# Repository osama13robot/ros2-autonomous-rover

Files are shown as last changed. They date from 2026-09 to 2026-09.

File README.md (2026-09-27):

# ROS 2 Autonomous Rover

**Two 3D-printable robots you can simulate, drive, and watch map a house by themselves, built to learn ROS 2 from.**







| **rover**: 2WD differential drive | **rover4**: 4WD with Ackermann steering | A map built completely autonomously |
|---|---|---|
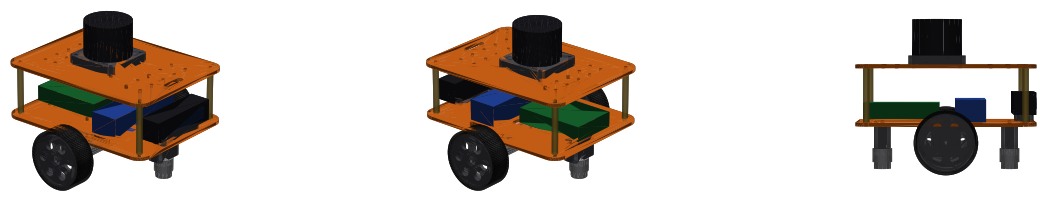
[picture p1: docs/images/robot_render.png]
rover
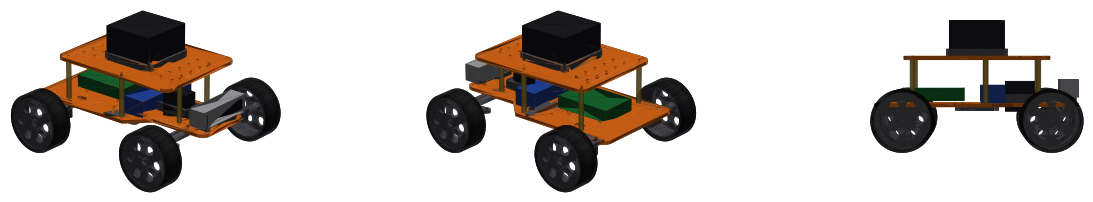
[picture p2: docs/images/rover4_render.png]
rover4
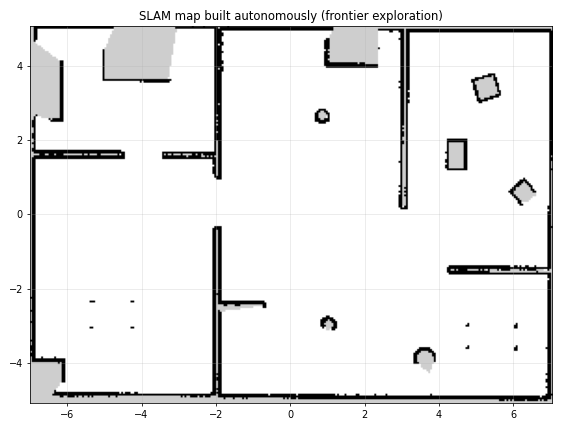
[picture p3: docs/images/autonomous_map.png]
map
|  |  |  |

This repository is a complete, working ROS 2 workspace for two small robots that share one
autonomy stack: **rover**, a 2WD differential-drive robot that turns in place, and **rover4**, a car-like
4WD robot with servo-steered front wheels, a RealSense D435i and an RPLIDAR S2M1. It covers the whole
stack, from the printable STL files to autonomous exploration, and every piece is documented so you
can understand it and change it.

## Features

| | |
|---|---|
| 🚗 **Two robots, one stack** | `robot:=rover` (2WD, turns in place) or `robot:=rover4` (4WD Ackermann steering), same topics and the same autonomy |
| 🖨️ **3D-printable hardware** | 9 + 15 printed parts generated by a parametric Python script, all fitting a 220 × 220 mm bed, with BOMs and assembly guides |
| 📐 **One source of truth** | a single `dimensions.yaml` drives the printable parts *and* the simulated robot, so they never disagree |
| 🌍 **Gazebo Harmonic simulation** | a 14 × 10 m indoor world with rooms, doorways, furniture and *low obstacles the lidar can't see* |
| 👀 **Sensors** | 360° lidar (RPLIDAR C1 / S2M1), RGB-D depth camera (RealSense D435 / D435i), IMU, wheel encoders |
| 🧭 **Localization** | EKF sensor fusion (wheel odometry + IMU), SLAM mapping, or AMCL on a saved map |
| 🗺️ **Navigation** | Nav2 with Smac planners (2D, or Hybrid-A* for the car), MPPI controller, 3D voxel costmaps that use the depth camera, and a collision monitor |
| 🤖 **Autonomous exploration** | a frontier explorer that maps unknown space by itself, then drives back home |
| 🎮 **Manual and autonomous modes** | drive with the keyboard; one key switches between MANUAL and AUTO, and any drive key takes over |
| 🧪 **Learning material** | 15 guides, 8 hands-on labs, a runnable Nav2 Python example, unit tests and CI |

## Quick start (about 15 minutes)

On **Ubuntu 24.04** with **ROS 2 Jazzy** installed ([full install guide](docs/01_installation.md)):

```bash
sudo apt install ros-jazzy-ros-gz ros-jazzy-navigation2 ros-jazzy-slam-toolbox \
  ros-jazzy-robot-localization ros-jazzy-xacro ros-jazzy-joint-state-publisher-gui python3-scipy
git clone https://github.com/osama13robot/ros2-autonomous-rover.git ~/ros2-autonomous-rover
cd ~/ros2-autonomous-rover
source /opt/ros/jazzy/setup.bash
colcon build --symlink-install
./scripts/start_sim.sh
```

Gazebo and RViz open, followed by a keyboard window. Click into the keyboard window, then:

* hold **`w a s d`** to drive
* press **`2`** to switch to **AUTO**: the robot starts exploring and mapping by itself
* press any drive key to take back control

For the 4WD car-like robot, add `robot:=rover4`: `./scripts/start_sim.sh robot:=rover4`.

Next: [Quick start guide](docs/02_quick_start.md) → [Hands-on labs](docs/10_hands_on_labs.md).

## Documentation

| # | Guide | You will learn |
|---|---|---|
| 00 | [Learning path](docs/00_learning_path.md) | where to start based on your level; glossary |
| 01 | [Installation](docs/01_installation.md) | installing ROS 2 Jazzy + Gazebo, building the workspace |
| 02 | [Quick start](docs/02_quick_start.md) | driving, going autonomous, saving and reusing maps |
| 03 | [Architecture](docs/03_architecture.md) | packages, nodes, topics, TF tree, launch files |
| 04 | [Robot design](docs/04_robot_design.md) | URDF/xacro, frames, sensors, parametric design |
| 05 | [Simulation](docs/05_simulation.md) | Gazebo worlds, plugins, the ROS bridge, sensor quirks |
| 06 | [Localization and mapping](docs/06_localization_and_mapping.md) | EKF, SLAM Toolbox, AMCL |
| 07 | [Navigation](docs/07_navigation.md) | Nav2: planner, controller, costmaps, collision monitor |
| 08 | [Manual and auto modes](docs/08_manual_and_auto_modes.md) | the velocity multiplexer and safety design |
| 09 | [Autonomous exploration](docs/09_autonomous_exploration.md) | the frontier exploration algorithm |
| 10 | [Hands-on labs](docs/10_hands_on_labs.md) | 8 guided exercises |
| 11 | [Building the real robot](docs/11_real_robot.md) | hardware bring-up, the driver topic contract |
| 12 | [Troubleshooting](docs/12_troubleshooting.md) | common problems and fixes |
| 13 | [Future possibilities](docs/13_future_possibilities.md) | a roadmap of extensions, ordered by difficulty |
| 14 | [Rover4: 4WD Ackermann](docs/14_rover4_ackermann.md) | car-like steering, Hybrid-A*, the second robot |
| – | [Hardware guide](hardware/README.md) | printable parts, BOMs, assembly, wiring (both robots) |

## Repository layout

```
ros2-autonomous-rover/          ← the repo is also the colcon workspace
├── src/
│   ├── rover_description/      robot models (rover, rover4): URDF/xacro, meshes, dimensions
│   ├── rover_gazebo/           simulation: worlds, spawning, Gazebo <-> ROS bridge
│   ├── rover_navigation/       EKF, SLAM, AMCL, Nav2 configs per robot, behavior trees, demo map
│   ├── rover_control/          Python nodes: teleop, mode manager, explorer, patrol example
│   └── rover_bringup/          top-level launch files (sim and real robot), RViz, parameters
├── hardware/                   parametric STL generator, printable parts, BOM
├── scripts/                    start_sim.sh, save_map.sh
└── docs/                       the guides listed above
```

## What has been tested

Everything below was run in simulation on the reference machine (Ubuntu 24.04, ROS 2 Jazzy,
Gazebo Harmonic 8.7, CPU-only rendering):

* **Drive base:** 0.3 m/s for 4 s gave 1.20 m of odometry; a commanded 90° turn measured 90.0°.
* **Autonomous exploration:** 131 m² mapped with no human input, then the robot drove back to the
  start. The SLAM pose was within about 1 cm of Gazebo's ground truth.
* **Saved-map navigation (AMCL):** reached a goal in another room, 6 cm from ground truth.
* **Waypoint patrol example:** all 5 waypoints across 4 rooms reached, finishing back home.
* **Low-obstacle avoidance:** the robot went around a 10 cm brick that the lidar can't see, using
  only the depth camera, with 0.41 m of clearance.
* **Mode switching:** keyboard commands pass only in MANUAL; switching to MANUAL cancels Nav2 goals; a
  drive key in AUTO takes over.
* **Unit tests:** `colcon test` passes 4 tests covering frontier detection and the velocity logic.
* **Printable parts:** all 9 + 15 STL files are verified watertight by the generator.
* **rover4 (4WD Ackermann):** measured steering angles match Ackermann geometry (25.3° / 18.9° vs. 25.5° / 19.0°
  in theory); autonomous exploration mapped 128 m² and returned home; SLAM pose within about 1 cm of ground truth.

The real-robot driver launch (`robot.launch.py`) is a **template that has not been tested on hardware**.
See [Building the real robot](docs/11_real_robot.md).

## Contributing

Contributions are welcome, from fixing a typo to adding a new world. See [CONTRIBUTING.md](CONTRIBUTING.md).

## License

[Apache License 2.0](LICENSE)

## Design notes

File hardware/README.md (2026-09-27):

# Hardware: 3D-printable parts, BOM, assembly

Two robots: the 2WD **rover** (this first section) and the 4WD Ackermann **rover4**
([jump to rover4](#rover4-4wd-ackermann)).

## Rover (2WD differential drive)

robot

A two-deck differential-drive robot, 200 × 206 × 171 mm, about 1 kg. Every structural part
fits a 220 × 220 mm print bed.

### Printable parts

The STL files are in `stl/`. They are generated from **`generate_parts.py`**, which reads
`../src/rover_description/config/dimensions.yaml`, the same file the URDF and
simulator use. Change a dimension there, then run:

```bash
python3 generate_parts.py --check   # regenerates stl/*.stl + sim meshes, verifies they are watertight
```

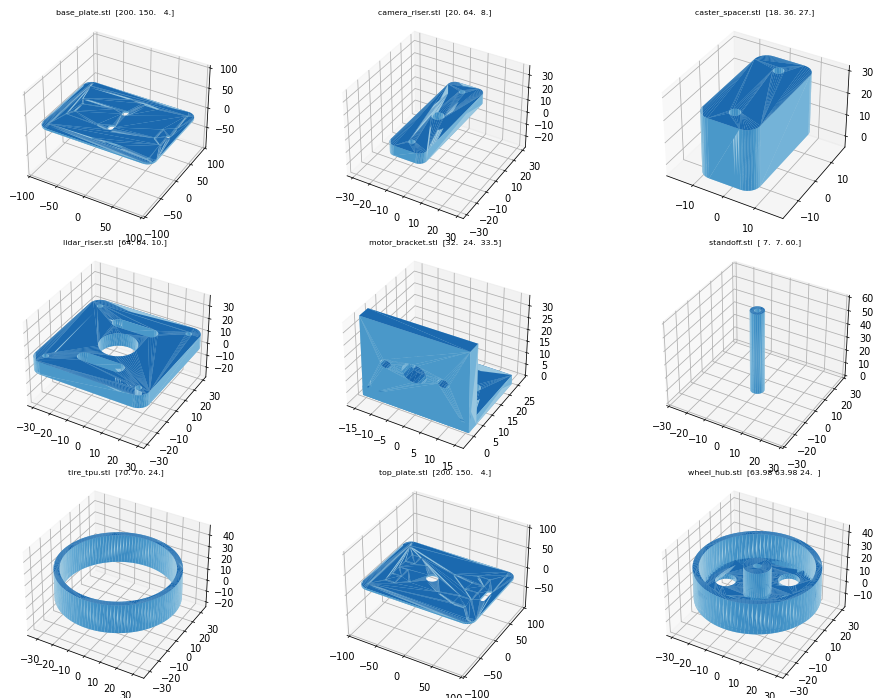
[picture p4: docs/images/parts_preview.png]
parts


| Part | Qty | Material | Notes |
|---|---|---|---|
| `base_plate.stl` | 1 | PETG / PLA | lower deck: motor brackets, casters, Pi 5, battery straps, camera riser |
| `top_plate.stl` | 1 | PETG / PLA | upper deck: lidar riser + M3 accessory grid |
| `wheel_hub.stl` | 2 | PETG | print outer face down; D-shaft press fit (4 mm JGA25 shaft) |
| `tire_tpu.stl` | 2 | TPU 95A | stretch over the hub rim |
| `motor_bracket.stl` | 2 | PETG | L-bracket, print flange down, 40 % infill |
| `caster_spacer.stl` | 2 | PETG / PLA | raises a 3/4" ball caster to the axle plane |
| `lidar_riser.stl` | 1 | PETG / PLA | |
| `camera_riser.stl` | 1 | PETG / PLA | 1/4"-20 screw from below into the camera |
| `standoff.stl` | 4 | PETG / PLA | or M3 × 60 mm brass standoffs |

Suggested print settings: 0.2 mm layers, 4 perimeters, 30 % gyroid infill, no supports.

### Bill of materials (non-printed)

| Item | Qty | Suggested part | Used for |
|---|---|---|---|
| Single-board computer | 1 | Raspberry Pi 5 (4–8 GB) + active cooler | runs ROS 2 Jazzy (Ubuntu 24.04) |
| Microcontroller | 1 | ESP32 / Raspberry Pi Pico | motor PWM + encoder counting (micro-ROS or serial) |
| Gear motors with encoders | 2 | JGA25-370, 12 V, 280 rpm, hall encoder | drive, **wheel odometry** |
| Motor driver | 1 | TB6612FNG or DRV8833 (2-channel) | |
| 2D lidar | 1 | Slamtec RPLIDAR C1 (or A1 / LDRobot LD19) | SLAM, localization, obstacles |
| RGB-D camera | 1 | Intel RealSense D435 / Luxonis OAK-D Lite | **low obstacles** the lidar can't see, images |
| IMU | 1 | BNO055 / ICM-20948 / MPU-6050 breakout | gyro for the EKF (slip-tolerant heading) |
| Ball casters | 2 | 3/4" metal ball caster (≈25 mm tall) | measure yours → `caster.body_height` |
| Battery | 1 | 3S LiPo 2200 mAh (or 3S 18650 pack + BMS) | |
| Step-down converter | 1 | 5 V / 5 A buck (USB-C PD trigger for the Pi 5) | |
| Power switch + fuse | 1 | 10 A rocker + inline 5 A fuse | |
| Screws | – | M3 × 8/10/12, M2.5 × 6 (Pi), 1/4"-20 × 8 (camera), M3 nuts / heat inserts | |

### Assembly

1. **Motors:** bolt each JGA25 gearbox face to a `motor_bracket` wall (2 × M3 × 6, 17 mm spacing).
   Bolt the bracket flanges under the base plate (2 × M3 each, holes 10 mm either side of the centre line).
2. **Wheels:** push the `tire_tpu` onto the `wheel_hub` (warm it slightly), then press the hub onto the D-shaft.
3. **Casters:** M3 screws through the base plate → `caster_spacer` → ball caster, front and rear.
4. **Electronics (lower deck, top side):** Pi 5 on M2.5 standoffs (rear), battery with a velcro
   strap through the slots (front), IMU at the centre, motor/encoder wires through the side slots.
5. **Camera:** `camera_riser` at the front edge (2 × M3), camera on the 1/4"-20 screw, facing forward.
6. **Upper deck:** 4 standoffs, then the `top_plate`; `lidar_riser` + lidar on top (cable through the centre hole).
   Motor driver, buck converter and switch go on the accessory grid.

### Wiring overview

```
3S battery ─ fuse ─ switch ─┬─ motor driver VM ── motors
                            └─ 5 V buck ── Raspberry Pi 5 ──USB── lidar
                                                   │ ├──USB3── RGB-D camera
                                                   │ └──I2C─── IMU
                                                   └──USB/UART── ESP32 ── motor driver (PWM/DIR)
                                                                   └───── encoders (A/B)
```

The ESP32 firmware must accept `/cmd_vel` and publish wheel odometry and joint states (see the
topic contract in [Building the real robot](../docs/11_real_robot.md)).

Sensor mounting positions in the URDF: lidar scan plane about 156 mm above the ground, camera
centre about 77 mm above the ground, 88 mm forward of the axle.

---

## Rover4 (4WD Ackermann)

rover4

A car-like robot: 4 driven wheels, servo-steered front wheels, RPLIDAR S2M1 and RealSense
D435i. It measures 285 × 250 × 179 mm and weighs about 2 kg. The design and the software are
explained in [docs/14](../docs/14_rover4_ackermann.md).

```bash
python3 generate_parts.py --robot rover4 --check    # → stl/rover4/*.stl (all fit a 220 × 220 mm bed)
```

Dimensions: `../src/rover_description/config/dimensions_rover4.yaml`.

### Printable parts (`stl/rover4/`)

| Part | Qty | Material | Notes |
|---|---|---|---|
| `base_rear.stl` | 1 | PETG | lower deck, rear half: rear motor clamps, Pi 5, cable slots |
| `base_front.stl` | 1 | PETG | lower deck, front half: battery straps, servo opening, beam and camera holes |
| `splice_plate.stl` | 1 | PETG | joins the two halves from below (6 × M3) |
| `top_plate.stl` | 1 | PETG / PLA | upper deck: lidar riser, accessory grid |
| `front_beam.stl` | 1 | PETG | front axle beam with the two M4 kingpin holes; 50 % infill |
| `knuckle_left.stl` / `knuckle_right.stl` | 1 + 1 | PETG | steering knuckle: kingpin boss, steering arm, N20 clamp; 5 perimeters |
| `rear_motor_clamp.stl` | 2 | PETG | N20 clamp under the rear deck |
| `servo_mount.stl` | 1 | PETG | MG996R frame; the servo shaft points down through the deck |
| `tie_rod.stl` | 2 | PETG | servo horn → steering arm |
| `wheel_hub.stl` | 4 | PETG | outer face down; 3 mm D-shaft press fit |
| `tire_tpu.stl` | 4 | TPU 95A | |
| `lidar_riser.stl` | 1 | PETG / PLA | **check the S2M1 hole pattern** (`lidar.mount_hole_spacing`) before printing |
| `camera_riser.stl` | 1 | PETG / PLA | D435i on a 1/4"-20 screw |
| `standoff.stl` | 6 | PETG / PLA | or M3 × 60 mm brass standoffs |

### Bill of materials (non-printed)

| Item | Qty | Suggested part | Used for |
|---|---|---|---|
| Single-board computer | 1 | Raspberry Pi 5, **8 GB** + active cooler | ROS 2 Jazzy; the D435i and 30 m lidar need more CPU and memory |
| Microcontroller | 1 | ESP32 (8 encoder interrupts + servo PWM) | 4 wheel speed loops, steering, odometry |
| Gear motors with encoders | 4 | N20 / GA12-N20, 12 V, ~200 rpm, hall encoder | 4-wheel drive |
| Motor drivers | 2 | TB6612FNG (2 channels each) | |
| Steering servo | 1 | MG996R (13 kg·cm) or DS3218 (20 kg·cm), metal 25T horn | front steering |
| Servo power | 1 | 6 V / 5 A UBEC | **separate supply**: the servo would brown out the Pi |
| 2D lidar | 1 | Slamtec RPLIDAR S2M1 (DFRobot), 1 Mbaud UART + USB adapter | SLAM, obstacles, 30 m range |
| RGB-D camera + IMU | 1 | Intel RealSense D435i (USB 3) | low obstacles, images, gyro for the EKF |
| Battery | 1 | 3S LiPo 2200–3000 mAh | |
| Step-down converter | 1 | 5 V / 5 A (USB-C PD for the Pi 5) | |
| Kingpins | 2 | M4 × 25 bolt + nylock nut + 2 washers | knuckle pivots |
| Tie-rod ends | 4 | M3 ball links (or M3 shoulder screws) | steering linkage |
| Screws | – | M3 × 8/10/12, M2.5 × 6 (Pi), 1/4"-20 × 8 (camera), M3 nuts / heat inserts | |

### Assembly

1. **Deck:** place `base_rear` and `base_front` edge to edge, bolt `splice_plate` underneath (6 × M3).
2. **Rear drive:** press an N20 into each `rear_motor_clamp`, bolt the clamps under the rear half (2 × M3 each).
3. **Front axle:** bolt `front_beam` under the front half (2 × M3). Press an N20 into each knuckle,
   then fit each knuckle under a beam end with an **M4 kingpin**. Tighten until it turns freely
   without play (nylock nut).
4. **Steering:** mount the servo in `servo_mount` over the deck opening, shaft down. Centre the servo
   (1500 µs) **before** fitting the horn pointing backwards. Connect the horn to both knuckle arms with the
   `tie_rod`s. Check both wheels point straight, then turn to full lock each way: **the tires must not
   touch the beam or the deck**. If they do, reduce `steering.limit` in the YAML and in the firmware.
5. **Wheels:** tires onto hubs, hubs onto the D-shafts.
6. **Electronics:** Pi 5 (rear), battery (front, strapped), ESP32 + 2 × TB6612 + UBEC on the upper
   deck grid; D435i on `camera_riser` at the nose.
7. **Upper deck:** 6 standoffs, `top_plate`, then `lidar_riser` + S2M1.

### Wiring overview

```
3S battery ─ fuse ─ switch ─┬─ 2 × TB6612 VM ── 4 × N20 motors
                            ├─ 6 V UBEC ─────── MG996R servo  (signal from ESP32)
                            └─ 5 V buck ─────── Raspberry Pi 5 ──USB── RPLIDAR S2M1
                                                       │ └─USB3── RealSense D435i (RGB-D + IMU)
                                                       └─USB── ESP32 ── 2 × TB6612 (PWM/DIR), servo PWM
                                                                  └──── 4 × encoders (A/B)
```

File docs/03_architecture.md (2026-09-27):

# 03 · Architecture

## Packages

| Package | Type | Responsibility |
|---|---|---|
| `rover_description` | CMake (data) | what the robot **is**: URDF/xacro, meshes, `dimensions.yaml` |
| `rover_gazebo` | CMake (data) | the **simulated world**: SDF worlds, spawning, Gazebo ↔ ROS bridge |
| `rover_navigation` | CMake (data) | **where am I, and how do I get there**: EKF, SLAM, AMCL, Nav2 configs and launch files |
| `rover_control` | Python | **custom behaviour**: teleop, mode manager, explorer, patrol example, sim adapter |
| `rover_bringup` | CMake (data) | **wiring it all together**: top-level launch files, RViz config, parameters |

Why split it like this? Each package can be reused alone. `rover_navigation` has no idea whether
it runs in Gazebo or on the real robot, and `rover_description` can be shown in RViz without
anything else. This is the standard ROS layout.

## Node graph

```mermaid
flowchart LR
    subgraph Gazebo["Gazebo Harmonic"]
        GZ[physics + sensors]
    end
    GZ -- "/scan" --> SLAM
    GZ -- "/camera/depth/points_raw" --> ADP[sim_sensor_adapter]
    GZ -- "/wheel/odometry, /imu" --> ADP
    ADP -- "/wheel/odometry_cov, /imu/data" --> EKF[ekf_filter_node]
    ADP -- "/camera/depth/points" --> NAV
    GZ -- "/scan" --> NAV
    EKF -- "TF odom→base_footprint<br>/odometry/filtered" --> NAV
    SLAM[slam_toolbox] -- "/map, TF map→odom" --> NAV
    SLAM -- "/map" --> EXP[frontier_explorer]
    EXP -- "navigate_to_pose (action)" --> NAV[Nav2]
    NAV -- "/cmd_vel_nav" --> MM[mode_manager]
    KEY[teleop_keyboard] -- "/cmd_vel_teleop, /mode_request" --> MM
    MM -- "/cmd_vel" --> GZ
    MM -- "/robot_mode" --> EXP
    MM -- "/robot_mode" --> KEY
```

## Topics you should know

| Topic | Type | Publisher → Subscribers |
|---|---|---|
| `/scan` | `sensor_msgs/LaserScan` | lidar → SLAM, AMCL, costmaps, collision monitor |
| `/camera/depth/points` | `sensor_msgs/PointCloud2` | sim adapter → costmaps, collision monitor |
| `/camera/color/image_raw` | `sensor_msgs/Image` | camera → RViz (and your future perception code) |
| `/imu/data` | `sensor_msgs/Imu` | sim adapter → EKF |
| `/wheel/odometry_cov` | `nav_msgs/Odometry` | sim adapter → EKF |
| `/odometry/filtered` | `nav_msgs/Odometry` | EKF → Nav2 |
| `/map` | `nav_msgs/OccupancyGrid` | SLAM / map_server → Nav2, explorer |
| `/cmd_vel_teleop` | `geometry_msgs/Twist` | keyboard → mode manager |
| `/cmd_vel_nav` | `geometry_msgs/Twist` | Nav2 collision monitor → mode manager |
| `/cmd_vel` | `geometry_msgs/Twist` | **mode manager only** → wheels |
| `/robot_mode` | `std_msgs/String` (latched) | mode manager → everyone: `MANUAL` / `AUTO` |
| `/explore/status` | `std_msgs/String` (latched) | explorer → keyboard status line |

See the live graph yourself with `rqt_graph`, and list everything with `ros2 topic list`.

## TF tree (coordinate frames)

```mermaid
flowchart TD
    map -->|"slam_toolbox or AMCL"| odom
    odom -->|"EKF (wheels + IMU)"| base_footprint
    base_footprint -->|"robot_state_publisher (URDF)"| base_link
    base_link --> left_wheel_link & right_wheel_link
    base_link --> front_caster_link & rear_caster_link
    base_link --> imu_link & lidar_link & camera_link
    camera_link --> camera_optical_link
```

* **`map → odom`**: corrects the slow drift of odometry. It can *jump* when SLAM closes a loop.
* **`odom → base_footprint`**: smooth and continuous, but drifts over time. Controllers use this.
* **`base_footprint`** is on the ground under the robot centre; **`base_link`** is on the wheel axle.

This split is the ROS convention [REP-105](https://www.ros.org/reps/rep-0105.html). See it live with
`ros2 run tf2_tools view_frames` (it writes `frames.pdf`).

## The velocity chain (who is allowed to move the robot)

```
Nav2 controller ──cmd_vel_nav_raw──► velocity_smoother ──cmd_vel_smoothed──► collision_monitor ──cmd_vel_nav──┐
                                                                                                               ├─► mode_manager ──cmd_vel──► wheels
teleop_keyboard ──cmd_vel_teleop───────────────────────────────────────────────────────────────────────────────┘
```

Exactly **one** node (`mode_manager`) writes `/cmd_vel`. This single point of control is what makes
the manual/auto switch safe and simple. See [08 Manual and auto modes](08_manual_and_auto_modes.md).

## Launch file hierarchy

```
rover_bringup/sim.launch.py                   ← what you run for simulation
├── rover_gazebo/sim.launch.py                   Gazebo + spawn + bridge + robot_state_publisher
├── rover_control sim_sensor_adapter             (node)
└── rover_bringup/autonomy.launch.py          ← shared with the real robot
    ├── rover_navigation/ekf.launch.py
    ├── rover_navigation/slam.launch.py          (if slam:=true)
    ├── rover_navigation/localization.launch.py  (if slam:=false: map_server + AMCL)
    ├── rover_control mode_manager               (node)
    ├── rviz2                                    (if rviz:=true)
    └── after 3 s: rover_navigation/navigation.launch.py (Nav2) + frontier_explorer

rover_bringup/robot.launch.py                 ← what you run on the real robot
├── robot_state_publisher, lidar driver, camera driver
└── rover_bringup/autonomy.launch.py
```

## Configuration files

| File | Controls |
|---|---|
| `rover_description/config/dimensions.yaml` | every physical dimension, mass and sensor spec |
| `rover_gazebo/config/gz_bridge.yaml` | which Gazebo topics are bridged to ROS |
| `rover_navigation/config/ekf.yaml` | sensor fusion |
| `rover_navigation/config/slam_toolbox.yaml` | mapping |
| `rover_navigation/config/nav2_params.yaml` | planning, control, costmaps, AMCL, safety |
| `rover_bringup/config/control.yaml` | mode manager, explorer, sim adapter |

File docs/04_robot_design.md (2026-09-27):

# 04 · Robot design

robot

## Concept

A classic **two-deck differential-drive** robot, the same layout as TurtleBot-style platforms:

* two driven wheels on a common axle at the centre, so it can **turn in place**
* front and rear ball casters for balance
* a lower deck for motors, battery and computer, and an upper deck for the lidar (clear 360° view)
* an RGB-D camera low at the front, where it sees what the lidar misses

| Property | Value |
|---|---|
| Size (L × W × H) | 200 × 206 × 171 mm |
| Mass | ~1 kg |
| Wheel radius / separation | 35 mm / 182 mm |
| Top speed (sim limit) | 0.5 m/s, autonomy uses ≤ 0.35 m/s |
| Lidar scan height | 156 mm |
| Camera height | 77 mm, 88 mm ahead of the axle |

## One source of truth: `dimensions.yaml`

`src/rover_description/config/dimensions.yaml` holds every dimension, mass and sensor setting.
Two very different programs read it:

```
dimensions.yaml ──► rover.urdf.xacro ──► simulation, TF frames, Nav2
               └──► hardware/generate_parts.py ──► printable STL files (+ meshes shown in the sim)
```

So if you make the wheels bigger, both the printed parts and the simulated robot change together.
This is the most important design idea in the project: **the model can't drift away from the real robot**.

In xacro, the YAML is loaded with:

```xml
<xacro:property name="d" value="${xacro.load_yaml('$(find rover_description)/config/dimensions.yaml')}"/>
<xacro:property name="R" value="${d['wheel']['radius']}"/>
```

## URDF structure

`urdf/rover.urdf.xacro` is organised as:

| Block | Contents |
|---|---|
| properties | derived heights (all relative to the wheel axle), wheel positions |
| `base_link` | both decks (STL meshes), standoffs, motors, electronics; **one** simple box for collision |
| `wheel` macro | a continuous joint about Y; visual = printed hub + tire meshes, collision = cylinder |
| `caster` macro | fixed sphere with **zero friction**, so it slides like a free ball |
| sensors | `imu_link`, `lidar_link`, `camera_link` + `camera_optical_link` |
| `rover.gazebo.xacro` | simulation-only plugins and sensors (included when `sim_gazebo:=true`) |

Design choices worth noticing:

* **Visual and collision geometry are different.** Visuals use detailed meshes (they look good);
  collisions use boxes, cylinders and spheres, which are fast and stable for the physics engine.
* **Inertia is computed by macros** (`inertial_macros.xacro`) from mass and size. Wrong inertia is a
  classic cause of robots that shake or fly away in simulation.
* **`camera_optical_link`** is rotated so that Z points forward, X right and Y down. This is the
  convention for camera images ([REP-103](https://www.ros.org/reps/rep-0103.html)); robot bodies use
  X forward, Y left, Z up.

## Sensors

| Sensor | Real part | Simulated as | Why it's there |
|---|---|---|---|
| 2D lidar | RPLIDAR C1 | `gpu_lidar`, 360 samples, 0.12–12 m, 10 Hz, σ = 1 cm | SLAM and localization need long-range 360° geometry |
| RGB-D camera | RealSense D435 | `rgbd_camera`, 424 × 240, 87° FOV, 0.2–6 m, 15 Hz | the lidar is a single plane at 15.6 cm, so the camera catches **lower and higher** obstacles |
| IMU | BNO055 / ICM-20948 | `imu`, 100 Hz, realistic noise and bias | its gyro measures rotation directly, even when the wheels slip |
| Wheel encoders | JGA25-370 hall encoders | `DiffDrive` odometry + `JointStatePublisher` | measure distance travelled; the backbone of odometry |

Each sensor covers a weakness of another:

* **Wheel odometry** is accurate over short distances but drifts, and it is wrong when a wheel slips.
* The **IMU gyro** is right during slips but drifts in heading over time.
* **Lidar SLAM** corrects long-term drift, but it only sees one horizontal plane.
* The **depth camera** sees in 3D, but only forward and at short range.

Combining them (sensor fusion) gives a system more reliable than any single sensor.

## Viewing and editing the robot

```bash
ros2 launch rover_description display.launch.py                  # with STL meshes
ros2 launch rover_description display.launch.py use_meshes:=false  # simple shapes
xacro src/rover_description/urdf/rover.urdf.xacro > /tmp/rover.urdf && check_urdf /tmp/rover.urdf
```

After changing `dimensions.yaml`:

```bash
python3 hardware/generate_parts.py --check   # new STL parts + sim meshes
colcon build --symlink-install               # meshes are installed files
```

Lab 1 in [Hands-on labs](10_hands_on_labs.md) walks you through this.

## Printable hardware

See the [Hardware guide](../hardware/README.md) for the parts list, BOM, print settings, assembly and wiring.

parts

The parts generator is itself a small lesson in computational geometry. Every part is a set of
**2.5D extrusions** (a 2D outline with holes, pushed up to a thickness). The script triangulates each
outline with **ear clipping** (holes are joined to the outline with "bridge" edges), builds the walls
and writes binary STL. `--check` verifies that every edge is shared by exactly two triangles, which
means the part is watertight and printable.

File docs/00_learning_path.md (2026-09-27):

# 00 · Learning path

This project is designed so you can learn from it in layers. First you run it and see it work,
then you understand how it works, then you change it.

## Who this is for

| You are… | Start with | Then |
|---|---|---|
| **New to ROS 2** (you know some Python and Linux) | [01 Installation](01_installation.md) → [02 Quick start](02_quick_start.md) | Labs 1–3, then guides 03 and 04 |
| **Familiar with ROS 2 basics** (nodes, topics, launch) | [02 Quick start](02_quick_start.md) → [03 Architecture](03_architecture.md) | Guides 06–09, then labs 4–7 |
| **Experienced with ROS / Nav2** | [03 Architecture](03_architecture.md) | [13 Future possibilities](13_future_possibilities.md): pick a project |
| **A maker who wants to build it** | [Hardware guide](../hardware/README.md) | [11 Real robot](11_real_robot.md), [14 Rover4](14_rover4_ackermann.md) |
| **Curious about car-like robots** | [14 Rover4: 4WD Ackermann](14_rover4_ackermann.md) | compare with guides 07 and 09 |
| **A teacher** | This page + [10 Hands-on labs](10_hands_on_labs.md) | Each lab is one class session (45–90 min) |

## Prerequisites

* **Computer:** Ubuntu 24.04, 4+ CPU cores, 8 GB RAM (16 GB recommended). A GPU helps a lot but is
  not required: the whole project was developed and tested with CPU-only rendering.
* **Skills:** basic terminal use (`cd`, `ls`, editing files) and reading Python. No robotics
  background is needed; concepts are explained as they come up.

## Suggested 4-week course

| Week | Topic | Guides | Labs |
|---|---|---|---|
| 1 | Run it, drive it, explore the ROS graph | 01, 02, 03 | 1, 2, 3 |
| 2 | Robot description and simulation | 04, 05 | (edit the robot in Lab 1) |
| 3 | Localization, mapping, navigation | 06, 07 | 4, 5, 6 |
| 4 | Autonomy and your own code | 08, 09 | 7, 8 + a project from guide 13 |

## How the pieces fit together (the 60-second version)

1. **Sensors** (lidar, depth camera, IMU, wheel encoders) publish data on **topics**.
2. An **EKF** fuses wheel odometry and IMU into a smooth estimate of how the robot moved.
3. **SLAM** uses the lidar to build a **map** and to work out where the robot is on it.
4. **Nav2** plans a path on that map and drives the robot along it while avoiding obstacles.
5. The **frontier explorer** picks the next unexplored spot and gives it to Nav2 as a goal.
6. The **mode manager** decides who is allowed to drive: you (keyboard) or Nav2.

## Glossary

| Term | Meaning |
|---|---|
| **Node** | a running program in ROS 2 (for example `mode_manager`) |
| **Topic** | a named data stream nodes publish to and subscribe from (for example `/scan`) |
| **Service** | a request/response call (for example `/set_autonomous`) |
| **Action** | a long-running goal with feedback and cancel (for example `navigate_to_pose`) |
| **TF** | the tree of coordinate frames (`map → odom → base_footprint → lidar_link …`) |
| **URDF / xacro** | XML description of the robot's links, joints, sensors; xacro adds variables and macros |
| **Odometry** | an estimate of motion from wheels/IMU; it drifts slowly over time |
| **EKF** | Extended Kalman Filter: combines noisy sensors into a better estimate |
| **SLAM** | Simultaneous Localization And Mapping: building a map while locating yourself in it |
| **AMCL** | Adaptive Monte Carlo Localization: locating the robot on an *existing* map using particles |
| **Costmap** | a grid saying how "expensive" (dangerous) each cell is for the robot |
| **Frontier** | the border between explored free space and unknown space |
| **Lifecycle node** | a node with managed states (unconfigured → inactive → active); Nav2 uses these |
| **Sim time** | in simulation, nodes use Gazebo's clock (`/clock`) instead of the wall clock |

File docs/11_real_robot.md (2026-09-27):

# 11 · Building the real robot

> This guide uses the 2WD **rover**; for **rover4** add `robot:=rover4` to the launch commands and see
> [14 Rover4](14_rover4_ackermann.md#real-robot-firmware-for-ackermann) for the steering firmware.

> **Status:** the mechanical design and the autonomy stack are complete and tested *in simulation*.
> The hardware bring-up described here is a **plan and a template**: the driver launch file has not
> been run on physical hardware yet. Contributions from people who build it are very welcome.

## 1. Build the hardware

Follow the [Hardware guide](../hardware/README.md): print the parts, buy the BOM, assemble and wire.
**Before printing**, measure your actual ball casters, motors and sensors, update
`dimensions.yaml`, and regenerate the parts.

## 2. Set up the computer (Raspberry Pi 5)

* Install **Ubuntu Server 24.04** (64-bit) and **ROS 2 Jazzy** (`ros-jazzy-ros-base` is enough on
  the robot; run RViz on your laptop).
* Clone this repository and build it (skip `rover_gazebo` to save time):
  `colcon build --symlink-install --packages-skip rover_gazebo`.
* Put the robot and the laptop on the same network with the same `ROS_DOMAIN_ID`.

## 3. The driver topic contract

The autonomy stack (`rover_bringup/autonomy.launch.py`) is exactly the same in simulation and on
the real robot. It expects these topics, which the drivers must provide:

| Direction | Topic | Type | Requirements |
|---|---|---|---|
| publish | `/scan` | `sensor_msgs/LaserScan` | `frame_id: lidar_link` |
| publish | `/camera/depth/points` | `sensor_msgs/PointCloud2` | frame must exist in the TF tree |
| publish | `/imu/data` | `sensor_msgs/Imu` | `frame_id: imu_link`, fill covariances; orientation covariance `[-1, …]` if there is no magnetometer |
| publish | `/wheel/odometry_cov` | `nav_msgs/Odometry` | twist from the encoders, `odom → base_footprint`, realistic twist covariance, **no TF** (the EKF publishes it) |
| publish | `/joint_states` | `sensor_msgs/JointState` | `left_wheel_joint`, `right_wheel_joint` positions in radians |
| subscribe | `/cmd_vel` | `geometry_msgs/Twist` | stop the motors if no message arrives for 0.5 s |

In simulation, Gazebo + `sim_sensor_adapter` provide exactly this contract.

## 4. Lidar and camera drivers

```bash
sudo apt install ros-jazzy-sllidar-ros2 ros-jazzy-realsense2-camera
ros2 launch rover_bringup robot.launch.py lidar:=true camera:=true
```

`robot.launch.py` configures:

* **sllidar_ros2** (RPLIDAR C1: 460800 baud, `frame_id: lidar_link`)
* **realsense2_camera** (424 × 240 at 15 Hz, point cloud on, its own TF off)

Check the frames the camera actually publishes: `ros2 topic echo --once /camera/depth/points --field header`.
If the frame (for example `camera_depth_optical_frame`) isn't in the URDF, either add it as a child
of `camera_link` in `rover.urdf.xacro`, or set the driver's frame parameters to match.

## 5. Motor controller firmware (to be written)

The microcontroller (ESP32 or Raspberry Pi Pico) needs to:

1. read both encoders (quadrature, interrupts or the PCNT peripheral on the ESP32),
2. run a **PID speed loop** per wheel (typically 50–100 Hz),
3. convert `/cmd_vel` → wheel speeds:
   `v_left = v − ω·L/2`, `v_right = v + ω·L/2` (L = 0.182 m, wheel radius 0.035 m),
4. integrate wheel travel into odometry and publish `/wheel/odometry_cov` and `/joint_states`,
5. apply the 0.5 s command timeout (safety).

Two common ways to connect it:

* **micro-ROS** on the ESP32: it becomes a ROS 2 node directly (USB serial or Wi-Fi via the
  `micro_ros_agent`).
* **A serial protocol** plus a small Python bridge node on the Pi: simpler to debug.

## 6. Bring-up checklist

| Step | Check |
|---|---|
| Wheels | `ros2 topic pub /cmd_vel …` with 0.1 m/s: both wheels turn forward |
| Encoders | push the robot by hand 1 m: `/wheel/odometry_cov` says about 1 m |
| Turning | command 1 rad/s for 6.28 s: the robot turns one full circle |
| IMU | rotate by hand: `/imu/data` `angular_velocity.z` is positive counter-clockwise |
| Lidar | RViz, fixed frame `base_footprint`: walls appear where they really are |
| TF | `ros2 run tf2_tools view_frames` matches [03 Architecture](03_architecture.md#tf-tree-coordinate-frames) |
| EKF | drive a square: `/odometry/filtered` returns close to the start |
| SLAM | map a room slowly in MANUAL |
| Nav2 | send short goals first, with `vx_max` reduced to 0.15 |
| Safety | lift the robot, then kill the teleop: the wheels must stop within 0.5 s |

## 7. Calibration

* **Wheel radius:** drive 2 m straight and measure; scale the radius by `actual / reported`.
* **Wheel separation:** spin 10 turns in place and compare with the reported angle; scale the
  separation the same way.
* **IMU:** keep the robot still at start-up for the gyro bias estimate (BNO055 does this internally).
* **Camera extrinsics:** make sure the camera pose in `dimensions.yaml` matches the real mount.
  Place a box in front of the robot and check that the point cloud and the lidar agree in RViz.

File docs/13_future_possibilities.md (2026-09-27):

# 13 · Future possibilities

The rover is a platform. Here are directions to take it, from weekend projects to research topics.
Each one lists what you'd learn and where to start in the code.

Difficulty: 🟢 beginner · 🟡 intermediate · 🔴 advanced

## Perception

| Project | | What you'd build | Starting point |
|---|---|---|---|
| **Object detection** | 🟡 | run a YOLO model on `/camera/color/image_raw`, publish `vision_msgs/Detection2DArray` | a new node; the camera is already bridged |
| **3D object positions** | 🟡 | combine detections with the depth image, so the robot knows *where* a chair is | depth is on `/camera/depth/image_raw` |
| **Semantic map** | 🔴 | label map regions ("kitchen", "door") from detections | a new costmap layer, or markers |
| **Person following** | 🟡 | detect a person, send moving goals, or drive directly in AUTO | `waypoint_patrol.py` is the template |
| **ArUco / AprilTag docking** | 🟡 | find a tag on a charging dock and drive onto it precisely | Nav2's `opennav_docking` is installed with Nav2 |
| **Cliff detection** | 🟢 | treat a *missing* floor in the depth image as an obstacle (stairs!) | extend the depth pipeline in `sim_sensor_adapter` |

## Mapping and localization

| Project | | What you'd build | Starting point |
|---|---|---|---|
| **3D RGB-D SLAM** | 🔴 | RTAB-Map with the depth camera for 3D maps and visual loop closure | `ros-jazzy-rtabmap-ros`, replace `slam.launch.py` |
| **Lifelong mapping** | 🟡 | keep updating a saved map as furniture moves | SLAM Toolbox `lifelong` mode |
| **Multi-floor maps** | 🔴 | switch maps when changing floor | Nav2 map server `load_map` service |
| **Better exploration** | 🟡 | information-gain frontiers, planner-based distances | `frontier_explorer.py`, see guide 09 |

## Navigation and behaviour

| Project | | What you'd build | Starting point |
|---|---|---|---|
| **Patrol scheduler** | 🟢 | patrol routes at set times, with a report of what was seen | `waypoint_patrol.py` |
| **Custom behavior tree** | 🟡 | a Nav2 BT XML, for example "try the goal; if blocked, wait 10 s, then try another route" | `bt_navigator` `default_nav_to_pose_bt_xml` |
| **Keepout / speed zones** | 🟢 | forbid areas and slow down near people | Nav2 costmap filters (a mask image) |
| **Assisted teleop mode** | 🟢 | keyboard driving that refuses to crash | Nav2 `assisted_teleop`, `mode_manager.py` |
| **Gamepad control** | 🟢 | `teleop_twist_joy` → `/cmd_vel_teleop`, a button → `/mode_request` | guide 08 |
| **Return to charge** | 🟡 | a battery model: when low, go to the dock | a battery plugin in Gazebo + docking |

## Interfaces

| Project | | What you'd build | Starting point |
|---|---|---|---|
| **Web dashboard** | 🟡 | map, camera, mode buttons in a browser (phone-friendly) | `rosbridge_suite` + roslibjs, or Foxglove |
| **Voice / natural-language commands** | 🟡 | "go to the kitchen", with a language model turning text into goals | named places → poses → `goToPose` |
| **Telemetry and logging** | 🟢 | record runs with `ros2 bag record`, analyse them offline | `ros2 bag` |

## Engineering

| Project | | What you'd build | Starting point |
|---|---|---|---|
| **Docker dev container** | 🟢 | one command to get a working environment on any OS | an `osrf/ros:jazzy-desktop-full` base image |
| **Simulation tests in CI** | 🟡 | a headless test that explores the world and checks the map area | the CI workflow in `.github/workflows` |
| **ros2_control** | 🟡 | replace the Gazebo DiffDrive plugin with `diff_drive_controller`, the same controller used on real hardware | `gz_ros2_control` is available |
| **C++ ports** | 🟡 | rewrite `mode_manager` in C++ (composable node) for lower latency | a good C++ ROS 2 exercise |
| **Parameter sweeps** | 🟡 | automatically run exploration with many parameter sets and compare | Lab 7, automated |

## Hardware

| Project | | What you'd build |
|---|---|---|
| **Bumper ring** | 🟢 | printed bumper + microswitches → a `/bumper` topic → an emergency stop |
| **Battery monitor** | 🟢 | an INA219 current/voltage sensor → `sensor_msgs/BatteryState` |
| **Outdoor variant** | 🔴 | bigger wheels, GPS + `navsat_transform`, outdoor Nav2 |
| **Small arm** | 🔴 | a 3-DOF printed arm on the top deck, with MoveIt 2 |
| **Mecanum wheels** | 🟡 | a holonomic drive: MPPI `motion_model: Omni` |
| **Per-wheel speeds for rover4** | 🟡 | drive each of the 4 wheels at its own Ackermann speed in simulation too (ros2_control `ackermann_steering_controller` or a custom Gazebo system), removing tire scrub |
| **4-wheel steering (rover4 → 4WS)** | 🔴 | steer the rear axle as well: tighter turns, crab motion; needs a custom controller and planner model |

## Research directions

* **Reinforcement learning** for local navigation, trained in this Gazebo world (a gym wrapper
  around `/cmd_vel` and `/scan`).
* **Multi-robot exploration**: several rovers, namespaced, sharing a map and splitting frontiers.
* **Sim-to-real studies**: measure how parameters tuned in simulation transfer to the real robot,
  and add noise and latency models to close the gap.
* **Learning-based perception for costmaps**: learn which depth points are traversable
  (thick carpet vs. a real step).

## Contributing a project

Pick one, open an issue saying you're working on it, and see [CONTRIBUTING.md](../CONTRIBUTING.md).
Add a guide in `docs/` for anything you build. Future learners will thank you.

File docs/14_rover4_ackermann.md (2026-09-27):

# 14 · Rover4: 4WD with Ackermann steering

rover4

Rover4 is the second robot in this repository: a **car-like** robot with **all four wheels driven**
and the **front wheels steered** by one servo. It uses a **RealSense D435i** (RGB-D + IMU) and an
**RPLIDAR S2M1** (30 m range). Everything else is shared with the 2WD rover: the autonomy stack,
mode switching, exploration, the docs and the labs. Select it with `robot:=rover4`.

```bash
./scripts/start_sim.sh robot:=rover4                    # simulation + car-mode keyboard
./scripts/start_sim.sh robot:=rover4 initial_mode:=auto # explore by itself right away
ros2 launch rover_description display.launch.py robot:=rover4   # model + steering sliders in RViz
```

## Rover vs. Rover4

| | rover (2WD) | rover4 (4WD Ackermann) |
|---|---|---|
| Drive | 2 wheels, differential | 4 wheels driven (N20 motors) |
| Steering | by wheel speed difference | front wheels, one MG996R servo |
| Turn in place | ✅ | ✖ (min. turning radius ≈ 0.35 m) |
| Size (L × W × H) | 200 × 206 × 171 mm | 285 × 250 × 179 mm |
| Wheels | Ø70 mm | Ø85 mm |
| Lidar | RPLIDAR C1 (12 m) | RPLIDAR S2M1 (30 m, DTOF) |
| Depth camera | RealSense D435 | RealSense D435i |
| IMU | separate board | the D435i's built-in BMI055 |
| Reference frame | axle centre | **rear**-axle centre |
| Global planner | Smac 2D | **Smac Hybrid-A\*** (Reeds-Shepp) |
| Controller | MPPI DiffDrive | **MPPI Ackermann** |
| Behavior tree | Nav2 default | default **without Spin** |
| Printed parts | 9 designs | 15 designs |

## Ackermann steering in 3 minutes

When a car turns, all wheels must roll around **one common centre** on the line of the rear
axle, otherwise the tires scrub sideways. That means the **inner front wheel must steer more** than
the outer one:

```
          δ_inner = atan( L / (R − k/2) )        L = wheelbase   (0.200 m)
          δ_outer = atan( L / (R + k/2) )        k = kingpin distance (0.160 m)
                                                 R = turn radius of the rear-axle centre
```

The knuckles' **steering arms point towards the rear-axle centre**. With one tie rod per side,
this linkage produces roughly this unequal angle automatically; that's the "Ackermann geometry".

A velocity command `(v, ω)` becomes a turn radius `R = v / ω`. That's why a car can't turn in place:
for `v = 0`, `R = 0`, which would need infinite steering. The steering limit (30°) gives the
minimum radius `R_min = L / tan(30°) ≈ 0.35 m`; the navigation stack uses 0.40 m for margin.

**Measured in simulation** (turning with R = 0.5 m): inner wheel **25.3°**, outer **18.9°**;
the formula above gives 25.5° and 19.0°.

## Hardware

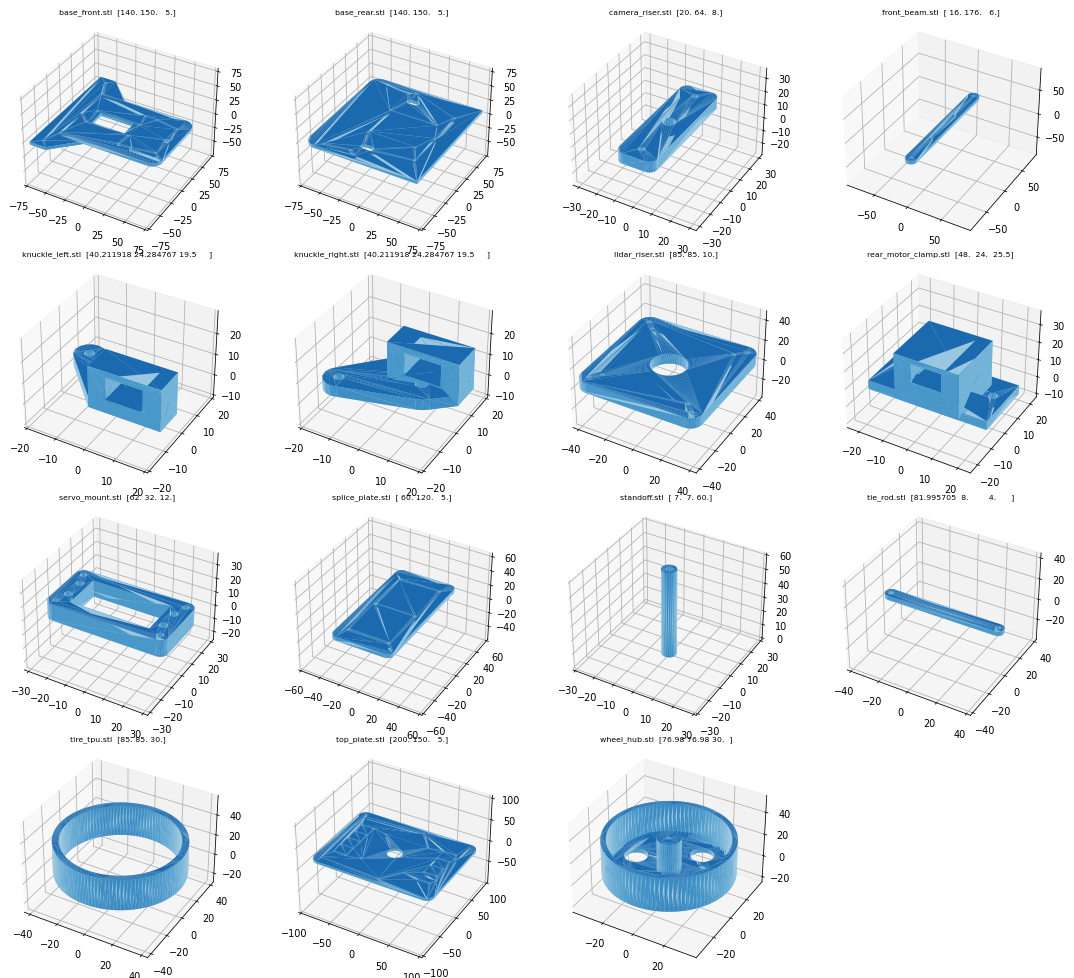
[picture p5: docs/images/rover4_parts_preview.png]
rover4 parts


The printable parts are generated from `src/rover_description/config/dimensions_rover4.yaml`:

```bash
python3 hardware/generate_parts.py --robot rover4 --check     # → hardware/stl/rover4/*.stl
```

The 280 mm lower deck doesn't fit a 220 mm bed, so it's printed as **two halves**, joined from
below by a **splice plate** with 6 × M3. Full parts list, BOM and assembly are in the
[hardware guide](../hardware/README.md#rover4-4wd-ackermann).

The steering chain: **MG996R servo** (shaft pointing down through the deck) → servo horn →
2 **tie rods** → **steering arms** on the 2 **knuckles**, which pivot on **M4 kingpins** in the
**front axle beam**. Each knuckle clamps an **N20 gear motor** that drives its wheel directly.

## Software: what changes for a car

**Simulation.** Gazebo's `AckermannSteering` system (in `rover4.gazebo.xacro`) takes the same
`/cmd_vel` as the 2WD rover and computes both steering angles and all four wheel speeds. It
publishes the same `/wheel/odometry`. The sensors publish the same topics too, so the
bridge, the sim adapter, the EKF, SLAM and the mode manager are **unchanged**.

**Planning: Smac Hybrid-A\*.** The 2D planner used by the rover finds paths a car can't drive
(sharp corners, turning on the spot). Hybrid-A\* searches over **(x, y, heading)** with motion
primitives that respect `minimum_turning_radius: 0.40`. With `REEDS_SHEPP` it may also reverse
(three-point turns); `reverse_penalty: 2.0` makes it prefer driving forwards.

**Control: MPPI Ackermann.** `motion_model: "Ackermann"` with
`AckermannConstraints.min_turning_r: 0.40` makes MPPI only sample trajectories the car can follow.

**Behavior tree.** Nav2's default recovery includes `Spin` (turn on the spot), which a car can't
do. `rover_navigation/behavior_trees/ackermann_*.xml` are the default trees without Spin:
clear costmaps → wait → back up. `navigation.launch.py robot:=rover4` loads them.

**Footprint.** The robot's reference point is the **rear axle** (the bicycle-model convention), so
the footprint polygon extends 0.255 m forwards and 0.055 m backwards.

**Keyboard.** `teleop_keyboard --ros-args -p ackermann:=true` (set automatically by
`start_sim.sh robot:=rover4`): `a`/`d` steer while rolling forwards; `q e z c` still work.

**Exploration.** `rover_bringup/config/control_rover4.yaml` keeps goals further from walls
(0.40 m) and from the robot (0.8 m), and allows more time per goal, because turning takes room.

All files: `nav2_params_rover4.yaml`, `control_rover4.yaml`, `rover4.urdf.xacro`,
`rover4.gazebo.xacro`, `dimensions_rover4.yaml`, `behavior_trees/ackermann_*.xml`.

## Results in simulation

| Test | rover (2WD) | rover4 (4WD Ackermann) |
|---|---|---|
| Autonomous exploration of the default world | 131 m², ≈ 4.4 min | **128 m², ≈ 8.8 min**, returned home |
| SLAM pose vs. ground truth at the end | ≈ 1 cm | **≈ 1 cm** |
| Real-time factor (headless, CPU rendering) | ≈ 0.4–0.9 | ≈ 0.85–0.9 |

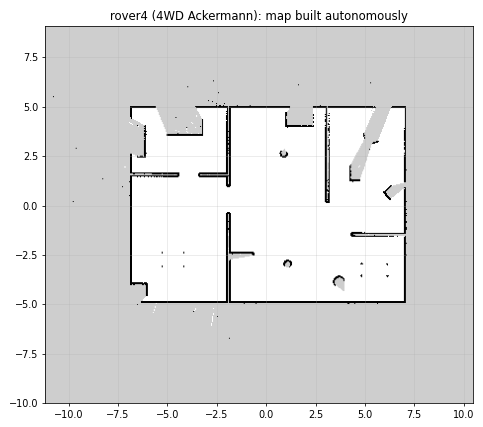
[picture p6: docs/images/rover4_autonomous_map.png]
rover4 map


Exploration takes about twice as long: every change of direction is a manoeuvre instead of a spin.

## Known limitations and things to check when building

* **Wheel odometry scrubs in turns.** In simulation, both wheels on a side turn at the same speed,
  but in a turn the front wheels travel further than the rear ones. Raw wheel odometry drifted about 26 cm
  over a 2.7 m run with a tight turn. The EKF (gyro) and SLAM correct this. On the real robot, the
  firmware can drive each wheel at its own speed (below).
* **Narrow spots.** Near walls and in 1.2 m doorways, the robot sometimes needs several attempts
  or a reverse manoeuvre. The explorer gives up on a goal after 30 s without progress and picks another.
* **The mechanical design is v1 and not test-fitted.** Check the tire clearance at full lock
  (reduce `steering.limit` if a tire rubs the beam), and the **S2M1 mounting hole pattern**
  (`lidar.mount_hole_spacing`) against the datasheet before printing.
* **The real-robot launch is a template**, as for the 2WD rover.

## Real robot: firmware for Ackermann

The driver contract is the same as for the rover ([11 Real robot](11_real_robot.md)): subscribe
`/cmd_vel`, publish `/wheel/odometry_cov` and `/joint_states`. `robot.launch.py robot:=rover4`
starts the S2M1 (1 Mbaud) and the D435i with its IMU remapped to `/imu/data`.

The microcontroller turns `(v, ω)` into servo and motor commands:

```text
if |v| < 0.01:                    steer = 0, all wheels 0            (a car cannot rotate in place)
R  = v / ω                        (turn radius of the rear-axle centre; straight if ω ≈ 0)
δ  = atan(L / R)                  → servo angle (clamp to ±30°; calibrate servo µs per degree)
rear  wheels:  v_rl = v (R − t/2)/R          v_rr = v (R + t/2)/R
front wheels:  v_fl = v √(L² + (R − t/2)²)/R  v_fr = v √(L² + (R + t/2)²)/R
                                  L = 0.200 m, t = 0.220 m, wheel radius 0.0425 m
```

Giving each wheel its own speed like this removes the tire scrub seen in the simulation. The
servo needs its **own 6 V supply** (a 5 A BEC). An MG996R draws up to 2.5 A under load and would
brown out the Raspberry Pi if they shared a regulator.

## Viewing the model

```bash
ros2 launch rover_description display.launch.py robot:=rover4   # move the steering + wheel sliders
xacro src/rover_description/urdf/rover4.urdf.xacro sim_gazebo:=false > /tmp/rover4.urdf && check_urdf /tmp/rover4.urdf
./scripts/start_sim.sh robot:=rover4 world:=empty.sdf   # drive it around an empty world
```

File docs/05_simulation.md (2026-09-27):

# 05 · Simulation

## The stack

```
Gazebo Harmonic (gz-sim 8)  ◄── ros_gz_sim "create" spawns the URDF from /robot_description
        │  gz-transport topics (/scan, /camera/points, /cmd_vel …)
        ▼
ros_gz_bridge parameter_bridge  (config: rover_gazebo/config/gz_bridge.yaml)
        │  ROS 2 topics
        ▼
rover_control/sim_sensor_adapter  →  the rest of the ROS system
```

Gazebo has its **own** messaging system (gz-transport), separate from ROS 2. The **bridge**
translates the topics listed in `gz_bridge.yaml`, in the direction given there:

```yaml
- ros_topic_name: /scan
  gz_topic_name: /scan
  ros_type_name: sensor_msgs/msg/LaserScan
  gz_type_name: gz.msgs.LaserScan
  direction: GZ_TO_ROS
```

Try `gz topic -l` (Gazebo side) next to `ros2 topic list` (ROS side) to see both worlds.

## The world: `rover_world.sdf`

A 14 × 10 m apartment/workshop built from simple static shapes:

| Feature | Why it's there |
|---|---|
| rooms connected by 1.2–1.5 m doorways | exploration has to find its way through doors |
| pillars, crates, a barrel | plenty of lidar features for SLAM |
| tables with thin legs | the lidar sees only four small dots, a realistic challenge |
| **low bricks, a step, a bin (8–10 cm)** | **below the lidar plane**, so only the depth camera can detect them |

`empty.sdf` is a flat ground, useful for testing the drive base.

The world file also loads the **system plugins** Gazebo needs:

```xml
<plugin filename="gz-sim-physics-system" .../>        <!-- physics -->
<plugin filename="gz-sim-sensors-system" ...>          <!-- rendering sensors: lidar, camera -->
  <render_engine>ogre2</render_engine>
</plugin>
<plugin filename="gz-sim-imu-system" .../>            <!-- IMU sensors -->
<plugin filename="gz-sim-scene-broadcaster-system" .../> <!-- GUI -->
<plugin filename="gz-sim-user-commands-system" .../>  <!-- spawning -->
```

A sensor declared in the URDF produces nothing unless its world-level system is loaded. This is a
very common beginner problem.

## Robot plugins (`rover.gazebo.xacro`)

* **DiffDrive** turns `/cmd_vel` into wheel speeds, with acceleration limits, and publishes
  wheel odometry. Its own TF output is deliberately *not* bridged, because the EKF publishes
  `odom → base_footprint`.
* **JointStatePublisher** publishes wheel angles on `/joint_states`, so the wheels turn in RViz.
* **Sensors** use `<gz_frame_id>` so their messages carry the correct URDF frame names.

## The sim sensor adapter: making simulation look like real drivers

`rover_control/sim_sensor_adapter.py` fixes three differences between Gazebo and real hardware
drivers:

1. **Covariances.** Gazebo's odometry and IMU messages don't carry meaningful covariances (how
   uncertain each value is). The EKF would then over-trust them. The adapter fills in realistic
   uncertainties, so the EKF weighs its sources properly.
2. **The point-cloud frame quirk.** Gazebo's RGB-D sensor publishes its point cloud with
   *x-forward* (body) axes while stamping it with the *optical* frame (z-forward). Left as is, every
   obstacle would appear in the wrong place. The adapter re-stamps the cloud with `camera_link`.
   This was found by measuring: the cloud's median point had x ≈ 0.8 m (forward) and z ≈ −0.07 m
   (the floor).
3. **Downsampling.** It keeps every 2nd pixel in each direction (4× fewer points), so the costmaps
   stay fast.

On the real robot this node is not used; the drivers publish these topics directly.

## Time in simulation

Every node runs with `use_sim_time: true` and reads the clock from `/clock` (Gazebo's time). If
the simulator runs at 0.5× real time, the whole robot "thinks" at half speed, and everything stays
consistent. Watch the real-time factor in the bottom-right corner of the Gazebo GUI.

## Performance tips

| Change | Effect |
|---|---|
| `headless:=true` | biggest win: no 3D GUI rendering |
| lower `camera.rate` or `image_width/height` in `dimensions.yaml` | less rendering work |
| lower MPPI `batch_size` in `nav2_params.yaml` | less CPU for the controller |
| `world:=empty.sdf` | fewer objects to render |

## Make your own world

1. Copy `rover_world.sdf` to `src/rover_gazebo/worlds/my_world.sdf`, keeping the `<plugin>` and
   `<light>` blocks.
2. Add models: a static `<model>` with a `<link>`, a `<collision>` and a `<visual>` (see the `box`
   and `cylinder` examples in the file), or include models from
   [Gazebo Fuel](https://app.gazebosim.org/fuel) with `<include><uri>https://fuel.gazebosim.org/...</uri></include>`.
3. Validate it: `gz sdf -k src/rover_gazebo/worlds/my_world.sdf` (prints `Valid.`).
4. Rebuild (a new file must be installed), then run `./scripts/start_sim.sh world:=my_world.sdf`.

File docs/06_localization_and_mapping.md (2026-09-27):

# 06 · Localization and mapping

"Where am I?" is answered in **two layers**, matching the two upper links of the TF tree:

```
map ──(SLAM or AMCL: corrects drift, may jump)──► odom ──(EKF: smooth, drifts)──► base_footprint
```

## Layer 1: the EKF (`robot_localization`)

**Goal:** a smooth, continuous estimate of motion at 30 Hz.

**Inputs** (`rover_navigation/config/ekf.yaml`):

| Source | Fused values | Why only these |
|---|---|---|
| `/wheel/odometry_cov` | forward speed `vx`, sideways speed `vy` (always 0), yaw rate `vyaw` | fuse **velocities**, not positions: they don't accumulate error inside the sensor |
| `/imu/data` | yaw rate `vyaw` | a gyro measures rotation directly, even when the wheels slip |

The 15-element `*_config` arrays select which of
`[x y z, roll pitch yaw, vx vy vz, vroll vpitch vyaw, ax ay az]` to use from each sensor.

`two_d_mode: true` tells the filter that the robot lives on a flat floor.

**Output:** the TF `odom → base_footprint` and the topic `/odometry/filtered`.

> **Why not use the wheel odometry directly?** Try [Lab 3](10_hands_on_labs.md#lab-3--odometry-and-sensor-fusion).
> When a wheel slips, wheel-only odometry believes the robot turned when it didn't. The gyro knows better.

## Layer 2a: SLAM Toolbox (mapping mode, the default)

**Goal:** build a map and keep the robot located in it. SLAM Toolbox is a graph-based SLAM:

1. Each new lidar scan (after the robot moves ≥ 0.2 m or turns ≥ 0.2 rad) is **scan-matched**
   against recent scans, which refines the odometry guess.
2. Scans become **nodes in a pose graph**, and the matches become edges.
3. When the robot returns to a known place, a **loop closure** adds an edge between distant nodes.
   The graph is then optimised (with the Ceres solver) and accumulated drift is removed.
4. The occupancy grid `/map` is re-rendered from the corrected poses every `map_update_interval`
   (2 s here).

It publishes `map → odom` (the correction) and `/map`.

Key parameters in `slam_toolbox.yaml`:

| Parameter | Value | Effect |
|---|---|---|
| `resolution` | 0.05 | 5 cm grid cells |
| `max_laser_range` | 12.0 | uses the full lidar range |
| `minimum_travel_distance` / `heading` | 0.2 / 0.2 | how often scans are added |
| `do_loop_closing` | true | the drift-removal magic |
| `map_update_interval` | 2.0 | faster map updates help the explorer |

**A detail you may notice:** right after start-up the map is almost empty. Cells only count as free
after a lidar ray has passed through them more than once, and new scans are only added after the
robot moves. The explorer handles this by requiring several empty evaluations in a row before it
declares a map "complete".

### Saving a map

```bash
./scripts/save_map.sh my_map
```

This runs `nav2_map_server map_saver_cli` and writes `my_map.pgm` (the image) and `my_map.yaml`
(resolution, origin, thresholds). In the image, black is occupied, white is free and grey is unknown.

## Layer 2b: AMCL (localization on a saved map)

With `slam:=false map:=<yaml>`, `map_server` publishes the stored map and **AMCL** (Adaptive Monte
Carlo Localization) tracks the robot on it:

1. It keeps 500–2000 **particles**, each one a guess of the robot pose.
2. When the robot moves, every particle moves by the odometry change plus noise (`alpha1..5`).
3. Each particle is scored by how well the current lidar scan fits the map from its pose
   (the likelihood field model).
4. Particles are resampled in proportion to their scores; wrong guesses die out.

It publishes `map → odom`. The start pose is set in `nav2_params.yaml`
(`set_initial_pose: true`, `initial_pose` at the origin). If you spawn the robot elsewhere, give AMCL
a hint with **2D Pose Estimate** in RViz.

## SLAM or AMCL?

| | SLAM (`slam:=true`) | AMCL (`slam:=false`) |
|---|---|---|
| Needs a map beforehand | no | yes |
| Map changes over time | yes (it keeps mapping) | no (fixed) |
| Exploration | ✅ | ✖ (nothing left to explore) |
| CPU | higher | lower |
| Typical use | first visit, changing places | daily operation in a known place |

## Measured accuracy (simulation)

* End of a full autonomous exploration: SLAM pose vs. Gazebo ground truth ≈ **1 cm**.
* AMCL on the saved map after crossing into another room: ≈ **6 cm**.

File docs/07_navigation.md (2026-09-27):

# 07 · Navigation (Nav2)

Nav2 turns "go to (x, y)" into wheel commands. All parameters are in
`src/rover_navigation/config/nav2_params.yaml`, and the servers are started by
`rover_navigation/launch/navigation.launch.py`.

## The servers

| Server | Job | Plugin used here |
|---|---|---|
| `bt_navigator` | runs a **behavior tree** that coordinates everything below | default "navigate with replanning and recovery" tree |
| `planner_server` | global path on the whole map | **Smac Planner 2D** (A* on the costmap) |
| `controller_server` | follows the path at 20 Hz, reacting to nearby obstacles | **MPPI** (Model Predictive Path Integral) |
| `smoother_server` | smooths paths on request | simple smoother |
| `behavior_server` | recovery actions: spin, back up, wait | spin / backup / wait / drive_on_heading |
| `velocity_smoother` | limits acceleration so motion isn't jerky | – |
| `collision_monitor` | a last safety check on every command | footprint "approach" model |
| `lifecycle_manager` | starts the servers in the right order | – |

The **behavior tree** plans a path, then follows it, and replans every second. If following
fails, it clears the costmaps, spins or backs up, and tries again, a few times, before giving up.

## Global planner: Smac 2D

A* search over the global costmap. `allow_unknown: true` lets it plan through unexplored space,
which is essential for exploration. `cost_travel_multiplier: 2.0` makes cells near obstacles
"expensive", so paths stay centred in corridors and doorways.

> This project first used NavFn and switched to Smac 2D after a test run showed NavFn failing to
> plan when the robot was already a few centimetres from the goal. This is a good example of
> choosing a plugin based on evidence.

## Controller: MPPI

MPPI simulates **1000 random trajectories** (`batch_size`) over 2.5 s (`time_steps × model_dt`) at
every control step. It scores them with **critics** and blends the best ones:

| Critic | Rewards |
|---|---|
| `CostCritic` | staying away from costly cells (obstacles) |
| `PathAlignCritic` / `PathFollowCritic` / `PathAngleCritic` | following the global path |
| `GoalCritic` / `GoalAngleCritic` | reaching the goal position and heading |
| `PreferForwardCritic` | driving forwards (the camera faces forward!) |
| `ConstraintCritic` | respecting velocity limits |

Speed limits: `vx_max: 0.35`, `vx_min: -0.20`, `wz_max: 1.5`.

## Costmaps: where the sensors meet the planner

A costmap is a grid where each cell is FREE (0), INSCRIBED/LETHAL (the robot would collide), or
somewhere in between (inflated, "better not"). This robot uses **two** costmaps:

| | Local costmap | Global costmap |
|---|---|---|
| Frame / size | `odom`, 3 × 3 m rolling window | `map`, whole map |
| Used by | controller (MPPI), collision checks | planner |
| Layers | **VoxelLayer** (lidar + depth) → inflation | static (map) → obstacle (lidar) → **depth VoxelLayer** → inflation |

### Why the depth camera needs special care

The lidar is a single horizontal plane at 15.6 cm. A 10 cm brick is invisible to it. The depth
camera sees the brick, but:

* **Floor points must be ignored**, otherwise the whole floor is an obstacle. So
  `min_obstacle_height: 0.04` (4 cm).
* **Table tops above the robot must be ignored**, so `max_obstacle_height: 0.35`.
* **The lidar must not erase what the camera saw.** In a flat (2D) layer, a lidar ray passing
  *above* the brick clears the brick's cell. That's why the depth data goes into a separate
  **VoxelLayer** (3D): each ray only clears the heights it actually passes through.

This design was validated with a test goal whose straight path crossed a 10 cm brick: the robot
went around it with 0.41 m of clearance.

> **Known behaviour while mapping:** whenever SLAM enlarges the map, the global costmap is resized
> and forgets depth-only obstacles. The local costmap still sees them, and it is what does the
> avoiding. With a saved map (AMCL) this doesn't happen.

### Footprint and inflation

* `footprint`: a 22 × 22 cm square polygon (the real outline plus padding). A polygon is more
  accurate than a circle for a boxy robot.
* `inflation_radius: 0.35`, `cost_scaling_factor: 4.0`: cost decays over 35 cm from obstacles.
  Raising the scaling factor lets the robot get closer; lowering it keeps it further away.

## Collision monitor: the last line of defence

It sits between Nav2 and the mode manager. Every 0.1 s it simulates the robot's footprint along the
**current** command for `time_before_collision: 0.6` s. If lidar or depth points would be hit, it
slows the command down, down to a stop. It is independent of the planner, so it still protects
the robot if the planner makes a mistake.

`source_timeout: 2.0`: if a sensor goes quiet for longer than this, the monitor stops the robot
(fail-safe). It is set generously because a slow simulator can deliver camera frames late.

## Recoveries and the progress checker

`progress_checker`: if the robot moves less than 0.3 m in 15 s, it's "stuck", and the behavior tree
starts recoveries. `general_goal_checker`: goals count as reached within 0.20 m and 0.30 rad.

## Tuning cheat sheet

| Symptom | Try |
|---|---|
| Too slow / too fast | MPPI `vx_max`, `velocity_smoother.max_velocity` |
| Cuts corners, grazes walls | increase `inflation_radius` or `cost_scaling_factor` ↓; CostCritic `cost_weight` ↑ |
| Won't go through doorways | `inflation_radius` ↓ (≥ 0.16, half the robot's diagonal) |
| Stops and starts near obstacles | collision monitor `time_before_collision` ↓ |
| Wobbly path following | PathAlign/PathFollow `cost_weight` ↑, `wz_std` ↓ |
| Floor shows up as obstacles | depth `min_obstacle_height` ↑ |
| CPU overloaded | MPPI `batch_size` ↓, `controller_frequency` ↓ |

Many parameters can be changed live, for example:

```bash
ros2 param set /local_costmap/local_costmap inflation_layer.inflation_radius 0.25
```

## Use Nav2 from your own code

See `src/rover_control/rover_control/waypoint_patrol.py`, which uses the **Nav2 Simple Commander**:

```python
nav = BasicNavigator()
nav.waitUntilNav2Active(localizer='robot_localization')
nav.goToPose(pose)
while not nav.isTaskComplete():
    ...
result = nav.getResult()   # SUCCEEDED / CANCELED / FAILED
```

Run it with `ros2 run rover_control waypoint_patrol --ros-args -p use_sim_time:=true`.

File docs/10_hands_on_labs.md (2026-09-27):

# 10 · Hands-on labs

Eight guided exercises, from "what is a topic?" to writing your own node. Each lab has a
**goal**, **steps**, ✅ **checkpoints** to confirm you're on track, and 🧠 **questions** to think
about. Suggested answers are at the end.

Before each lab, in every terminal:

```bash
source /opt/ros/jazzy/setup.bash && source ~/ros2-autonomous-rover/install/setup.bash
cd ~/ros2-autonomous-rover
```

> **Tip:** `headless:=true` makes everything faster; RViz shows all you need.

---

## Lab 1 · The robot model

*Time: ≈ 45 min*

**Goal:** understand the URDF, the TF frames, and the "single source of truth" design.

1. Show the robot: `ros2 launch rover_description display.launch.py`.
   Move the wheel sliders in the *Joint State Publisher* window.
2. In RViz, enable **TF → Show Names**. Find `base_footprint`, `base_link`, `lidar_link`,
   `camera_link` and `camera_optical_link`.
3. Print the generated URDF and find the lidar joint:
   ```bash
   xacro src/rover_description/urdf/rover.urdf.xacro sim_gazebo:=false | grep -A4 'joint name="lidar_joint"'
   ```
4. Open `src/rover_description/config/dimensions.yaml` and change:
   * `lidar.riser_height: 0.010` → `0.040` (lidar 3 cm higher)
   * `camera.pitch: 0.0` → `0.2` (camera tilted down about 11°)
5. Regenerate the parts and rebuild, then show the robot again:
   ```bash
   python3 hardware/generate_parts.py --check
   colcon build --symlink-install
   ros2 launch rover_description display.launch.py
   ```

✅ The lidar sits higher on a taller riser, and the camera looks down.
✅ `hardware/stl/lidar_riser.stl` is now 40 mm tall.

6. Revert both values, then regenerate and rebuild again.

🧠 **Q1.** Why is `base_footprint` on the ground but `base_link` on the wheel axle?
🧠 **Q2.** The collision geometry of the chassis is one box, but the visual is detailed meshes. Why?
🧠 **Q3.** Name one advantage and one drawback of tilting the camera down.

---

## Lab 2 · Exploring the ROS graph

*Time: ≈ 45 min*

**Goal:** learn the command-line tools every ROS developer uses daily.

Start the simulation: `./scripts/start_sim.sh headless:=true`.

1. Nodes and topics:
   ```bash
   ros2 node list
   ros2 topic list
   ros2 topic info /cmd_vel --verbose      # who publishes? who subscribes?
   ```
2. Data rates and content:
   ```bash
   ros2 topic hz /scan
   ros2 topic hz /camera/depth/points
   ros2 topic echo /robot_mode
   ros2 topic echo --once /scan --field range_max
   ```
3. The graph: `rqt_graph` (untick *Hide debug*, and choose *Nodes/Topics (all)*).
4. The TF tree: `ros2 run tf2_tools view_frames`, then open `frames_*.pdf`.
5. Where is the lidar, relative to the robot?
   ```bash
   ros2 run tf2_ros tf2_echo base_footprint lidar_link
   ```
6. Parameters:
   ```bash
   ros2 param list /mode_manager
   ros2 param get /mode_manager max_linear
   ```

✅ `/scan` runs at about 10 Hz (less if the sim is slower than real time).
✅ `tf2_echo` shows translation `[-0.010, 0.000, 0.156]`.
✅ `/cmd_vel` has exactly **one** publisher: `mode_manager`.

🧠 **Q4.** Why does `/robot_mode` show a value immediately, even though it's only published on changes?
🧠 **Q5.** Which node publishes `map → odom`? Which publishes `odom → base_footprint`?

---

## Lab 3 · Odometry and sensor fusion

*Time: ≈ 60 min*

**Goal:** see why the robot fuses wheel odometry and the IMU, and why SLAM is still needed.

1. Start the empty world: `./scripts/start_sim.sh headless:=true world:=empty.sdf`.
2. In a second terminal, watch the filtered estimate:
   ```bash
   ros2 topic echo /odometry/filtered --field pose.pose.position
   ```
3. In a third terminal, watch Gazebo's ground truth:
   ```bash
   gz topic -e -t /world/empty_world/dynamic_pose/info | grep -A3 'name: "rover"'
   ```
4. With the keyboard, drive a square of about 1 m sides (forward about 4 s at 0.25 m/s, then
   turn 90°, four times) and come back to the start.
5. Compare where the EKF thinks the robot is with the ground truth.
6. Look at the raw wheel odometry too: `ros2 topic echo /wheel/odometry_cov --field pose.pose.position`.

✅ In simulation the error is small: wheels don't slip much on a perfect floor.

7. **Experiment:** in `src/rover_navigation/config/ekf.yaml`, set the last `true` of
   `imu0_config` to `false` (so the IMU yaw rate is no longer used). Restart and repeat the square.
   Put it back afterwards.

🧠 **Q6.** Why does the EKF fuse *velocities* from the wheels instead of the position they report?
🧠 **Q7.** On a real robot on carpet, which would you trust more for turning: wheels or gyro? Why?
🧠 **Q8.** If the EKF is so good, why do we still need SLAM or AMCL?

---

## Lab 4 · Build a map with SLAM

*Time: ≈ 45 min*

**Goal:** map the world by hand, watch loop closure, save and reuse the map.

1. `./scripts/start_sim.sh` (keep the Gazebo GUI this time if your computer can handle it).
2. Stay in MANUAL. Drive slowly through **two rooms** and back to the start.
3. Watch the map in RViz while driving. Grey (unknown) becomes white (free) and black (walls).
4. When you come back near the start, look for a small "snap" of the map: that's a **loop closure**.
5. Save it: `./scripts/save_map.sh lab4`.
6. Open `src/rover_navigation/maps/lab4.pgm` in any image viewer, and read `lab4.yaml`.
7. Restart on your map (with AMCL instead of SLAM):
   ```bash
   ./scripts/start_sim.sh slam:=false map:=$PWD/src/rover_navigation/maps/lab4.yaml
   ```

✅ The robot appears on your map at the right place. Driving, the lidar dots stay aligned with the walls.

🧠 **Q9.** Driving fast and turning fast make SLAM maps worse. Why?
🧠 **Q10.** What does the `origin` field in `lab4.yaml` mean?

---

## Lab 5 · Sending navigation goals

*Time: ≈ 45 min*

**Goal:** command Nav2 in three different ways.

Start on the included map: `./scripts/start_sim.sh headless:=true slam:=false map:=$PWD/src/rover_navigation/maps/rover_world.yaml`,
then press `2` in the keyboard window (AUTO).

1. **RViz:** use *2D Goal Pose* to click a goal in another room. Watch the blue global path and the robot.
2. **Command line (action):**
   ```bash
   ros2 action send_goal /navigate_to_pose nav2_msgs/action/NavigateToPose \
     "{pose: {header: {frame_id: map}, pose: {position: {x: 5.0, y: 3.0}, orientation: {w: 1.0}}}}" --feedback
   ```
3. **Python:** the patrol example.
   ```bash
   ros2 run rover_control waypoint_patrol --ros-args -p use_sim_time:=true \
     -p waypoints:="[1.5, 2.0, 5.0, 3.0, 0.0, 0.0]"
   ```
4. While the patrol runs, press `w` in the keyboard window. What happens to the patrol?
5. Read `src/rover_control/rover_control/waypoint_patrol.py`. It's short.

✅ The action prints feedback (distance remaining) and ends with `SUCCEEDED`.
✅ Pressing a drive key cancels the patrol ("Goal cancelled (manual take-over?)").

🧠 **Q11.** What's the difference between a topic, a service and an action? Why is navigation an action?
🧠 **Q12.** Why must the robot be in AUTO for the goal to move it?

---

## Lab 6 · Costmaps and the depth camera

*Time: ≈ 60 min*

**Goal:** see how the depth camera protects the robot from obstacles the lidar can't see.

1. Start on the included map in AUTO (as in Lab 5).
2. Send a goal whose straight path crosses the **low red brick** at (2.0, −1.2):
   ```bash
   ros2 action send_goal /navigate_to_pose nav2_msgs/action/NavigateToPose \
     "{pose: {header: {frame_id: map}, pose: {position: {x: 3.6, y: -1.85}, orientation: {w: 1.0}}}}"
   ```
3. In RViz, watch the **local costmap** as the brick comes into the camera's view. It appears as an
   obstacle even though there are no red lidar dots on it.

✅ The robot curves around the brick.

4. **Experiment (the robot will hit the brick):** in `src/rover_navigation/config/nav2_params.yaml`,
   change `observation_sources: scan depth` to `observation_sources: scan` in the **local costmap**,
   remove `depth_layer` from the global costmap `plugins` list, and set `enabled: False` for the
   collision monitor's `depth` source. Restart and send the same goal (drive back to the origin first).
5. **Restore the file** (for example `git checkout src/rover_navigation/config/nav2_params.yaml`).

🧠 **Q13.** Why is the depth data kept in a *voxel* layer instead of a normal 2D obstacle layer?
🧠 **Q14.** Why is `min_obstacle_height` 0.04 rather than 0.0?

---

## Lab 7 · Tune the explorer

*Time: ≈ 60–90 min*

**Goal:** understand how parameter choices change autonomous behaviour.

1. Run a baseline exploration and time it:
   ```bash
   ./scripts/start_sim.sh headless:=true initial_mode:=auto
   ros2 topic echo /explore/status        # note the sim time when it says DONE
   ros2 topic echo --once /clock          # current sim time
   ```
2. Edit `src/rover_bringup/config/control.yaml` → `frontier_explorer`, one change per run:
   * **Greedy nearest:** `size_weight: 0.0`
   * **Big frontiers first:** `distance_weight: 0.2`
   * **Brave:** `clearance: 0.20`
3. Record, for each run: time to `DONE`, number of "Abandoning" or "Could not reach" messages in the
   launch output, and how complete the map looks.

✅ You have a small table comparing three strategies.

🧠 **Q15.** Why might "greedy nearest" produce a lot of back-and-forth driving?
🧠 **Q16.** What would go wrong if `done_confirmations` were 1?

---

## Lab 8 · Write your own node

*Time: ≈ 60 min*

**Goal:** create a ROS 2 Python package from scratch: a *proximity guard* that reports the closest
obstacle and warns when something is too near.

1. Create a package inside the workspace:
   ```bash
   cd ~/ros2-autonomous-rover/src
   ros2 pkg create --build-type ament_python my_rover_tools \
     --dependencies rclpy sensor_msgs std_msgs --node-name proximity_guard
   ```
2. Replace `my_rover_tools/my_rover_tools/proximity_guard.py` with:
   ```python
   import math

   import rclpy
   from rclpy.node import Node
   from rclpy.qos import qos_profile_sensor_data
   from sensor_msgs.msg import LaserScan
   from std_msgs.msg import Float32

   class ProximityGuard(Node):
       def __init__(self):
           super().__init__('proximity_guard')
           self.declare_parameter('warn_distance', 0.35)
           self.pub = self.create_publisher(Float32, '/closest_obstacle', 10)
           self.create_subscription(LaserScan, '/scan', self.on_scan, qos_profile_sensor_data)

       def on_scan(self, scan):
           valid = [(r, i) for i, r in enumerate(scan.ranges)
                    if math.isfinite(r) and scan.range_min < r < scan.range_max]
           if not valid:
               return
           dist, idx = min(valid)
           angle = math.degrees(scan.angle_min + idx * scan.angle_increment)
           self.pub.publish(Float32(data=dist))
           if dist < self.get_parameter('warn_distance').value:
               self.get_logger().warn(f'Obstacle {dist:.2f} m away at {angle:+.0f} deg',
                                      throttle_duration_sec=1.0)

   def main():
       rclpy.init()
       node = ProximityGuard()
       try:
           rclpy.spin(node)
       except (KeyboardInterrupt, rclpy.executors.ExternalShutdownException):
           pass                        # Ctrl-C: exit quietly
       finally:
           node.destroy_node()
           rclpy.try_shutdown()

   if __name__ == '__main__':
       main()
   ```
3. Build and run it:
   ```bash
   cd ~/ros2-autonomous-rover
   colcon build --symlink-install --packages-select my_rover_tools
   source install/setup.bash
   ros2 run my_rover_tools proximity_guard --ros-args -p use_sim_time:=true
   ```
4. With the sim running, drive towards a wall and watch the warnings. Also run
   `ros2 topic echo /closest_obstacle`.

✅ Warnings appear below 0.35 m, and the angle tells you where the obstacle is (0° = front, +90° = left).

**Challenges:**
* Publish a `visualization_msgs/Marker` arrow pointing at the closest obstacle and show it in RViz.
* Ignore obstacles behind the robot (only consider −60°…+60°).
* Make it change the robot's speed limit: study how `mode_manager` clamps speeds, and add a
  `/speed_scale` topic it listens to.

🧠 **Q17.** Why subscribe with `qos_profile_sensor_data` rather than the default QoS?

---

## Suggested answers

<details><summary>Click to reveal</summary>

**Q1.** REP-105: planners and costmaps work in 2D on the floor, so a ground-level frame is convenient
(`base_footprint`). Mechanical parts are naturally described from the axle (`base_link`).

**Q2.** Physics engines are much faster and more stable with simple shapes; meshes are only for looks.

**Q3.** Advantage: it sees low obstacles close to the robot. Drawback: it sees less far ahead and
less of tall obstacles, and more floor (so floor filtering matters more).

**Q4.** It's *latched* (`TRANSIENT_LOCAL` durability): the publisher re-sends the last message to
new subscribers.

**Q5.** `map → odom`: slam_toolbox (or AMCL). `odom → base_footprint`: the EKF (`ekf_filter_node`).

**Q6.** Positions from wheel odometry already contain accumulated error. Fusing velocities lets
the EKF integrate them itself and combine them properly with the other sensors.

**Q7.** The gyro. Wheels slip and skid on carpet, especially when turning; a gyro measures rotation
directly.

**Q8.** Any odometry (even fused) is integrated, so small errors pile up without limit. Only
comparing with the environment (lidar vs. map) corrects the drift.

**Q9.** Scan matching assumes consecutive scans overlap well and that the odometry guess is close.
Fast motion breaks both, and motion during a single lidar rotation distorts the scan.

**Q10.** The position of the lower-left pixel of the image in the `map` frame (x, y, yaw).

**Q11.** Topic: continuous one-way stream. Service: quick request/response. Action: a long task
with feedback and cancellation. Navigating takes time, reports progress, and must be cancellable,
so it's an action.

**Q12.** The mode manager only forwards Nav2's commands in AUTO. In MANUAL, Nav2 computes commands
but they never reach the wheels.

**Q13.** In a 2D layer, lidar rays passing *above* a low obstacle would clear its cell. In 3D, each
ray only clears the voxels it passes through.

**Q14.** Noise and small errors in the camera's pose would make floor points appear slightly above
zero, and the whole floor would become an obstacle.

**Q15.** It always takes the closest frontier, even a tiny one, and may leave big areas half-explored
and have to come back later.

**Q16.** Right after start-up the map is nearly empty, so there may be no valid frontier on the
first check. The explorer would end immediately (this actually happened during development).

**Q17.** `qos_profile_sensor_data` is *best effort* with a small queue: for sensors, a fresh
message matters more than a resent old one. A best-effort subscriber can receive from both reliable
and best-effort publishers, but a default *reliable* subscriber gets nothing from a best-effort
publisher, which many real lidar and camera drivers use.

</details>

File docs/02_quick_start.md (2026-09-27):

# 02 · Quick start

## Start everything

```bash
cd ~/ros2-autonomous-rover
./scripts/start_sim.sh
```

This starts Gazebo, RViz and the whole autonomy stack, and opens a second terminal window with the
keyboard control (after about 8 s). Without `gnome-terminal`, open a new terminal yourself and run:

```bash
ros2 run rover_control teleop_keyboard
```

> The keyboard node needs a **real interactive terminal**, so it can't run inside a launch file.

Useful variations (any `name:=value` is passed to the launch file):

```bash
./scripts/start_sim.sh headless:=true          # no Gazebo window (much faster), RViz only
./scripts/start_sim.sh initial_mode:=auto      # start exploring immediately
./scripts/start_sim.sh world:=empty.sdf        # flat empty world
./scripts/start_sim.sh robot:=rover4           # the 4WD car-like robot (keyboard in car mode)
```

## What you see

**Gazebo** shows the physical simulation: the robot in a 14 × 10 m apartment.

**RViz** shows what the robot *knows*:

| Display | Meaning |
|---|---|
| grey/black map | the SLAM map being built (black = wall, grey = unknown) |
| red dots | lidar hits |
| coloured points | the depth camera's 3D point cloud |
| blue/purple haze | costmaps: where the robot should not go |
| blue line | the planned path |
| green dots / blue spheres / red cylinder | frontier cells / candidate goals / current exploration target |
| camera panel | the RGB camera image |

## Drive it (MANUAL mode)

```
   q  w  e        hold a key to drive; release it and the robot stops (~0.6 s)
   a  s  d        w/x forward/back · a/d turn · q/e/z/c curves · s or SPACE stop
   z  x  c        arrow keys work too
   r/f  speed ±10 %     t/g  turn speed ±10 %
```

The status line at the bottom shows the mode, the speed, and the explorer's status.

## Go autonomous (AUTO mode)

Press **`2`** (or `m` to toggle). The robot will:

1. pick the most attractive **frontier** (border of unknown space),
2. plan a path and drive there, avoiding obstacles,
3. repeat until nothing unknown is reachable,
4. drive back to where it started, and report `DONE`.

Take over at any moment by pressing **any drive key**; the robot switches to MANUAL and cancels
its goal. Press `2` to hand control back. `o` pauses or resumes exploration.

### Send your own goal

In AUTO, click **2D Goal Pose** in the RViz toolbar, then click and drag on the map. The explorer
pauses (your goal wins); press `o` to resume exploring afterwards.

## Save the map, then navigate on it

When exploration reports `DONE`:

```bash
./scripts/save_map.sh my_apartment
# → src/rover_navigation/maps/my_apartment.yaml + .pgm
```

Next time, skip mapping and localize on the saved map with **AMCL**:

```bash
./scripts/start_sim.sh slam:=false map:=$HOME/ros2-autonomous-rover/src/rover_navigation/maps/my_apartment.yaml
```

A ready-made map of the default world is included, so you can try this immediately:

```bash
./scripts/start_sim.sh slam:=false map:=$HOME/ros2-autonomous-rover/src/rover_navigation/maps/rover_world.yaml
```

Then run the patrol example, which visits 5 rooms in turn:

```bash
ros2 run rover_control waypoint_patrol --ros-args -p use_sim_time:=true
```

## Control from the command line

Everything the keyboard does is also available as ROS interfaces:

```bash
ros2 topic pub --once /mode_request std_msgs/String "{data: auto}"   # manual | auto | toggle
ros2 service call /set_autonomous std_srvs/srv/SetBool "{data: false}"
ros2 service call /explore/enable std_srvs/srv/SetBool "{data: true}"
ros2 topic echo /robot_mode
ros2 topic echo /explore/status
```

## All launch arguments

`ros2 launch rover_bringup sim.launch.py <arg>:=<value>`:

| Argument | Default | Meaning |
|---|---|---|
| `robot` | `rover` | `rover` (2WD, turns in place) or `rover4` (4WD Ackermann, see [14](14_rover4_ackermann.md)) |
| `world` | `rover_world.sdf` | a world file from `rover_gazebo/worlds` |
| `headless` | `false` | run Gazebo without its GUI |
| `x`, `y`, `yaw` | `0.0` | spawn pose |
| `slam` | `true` | `true` = build a map; `false` = AMCL on `map` |
| `map` | `''` | map yaml (only with `slam:=false`) |
| `explore` | `true` | start exploring automatically when switched to AUTO |
| `initial_mode` | `manual` | `manual` or `auto` |
| `rviz` | `true` | start RViz |

## Stopping

Press **Ctrl-C** in the launch terminal. If Gazebo is still running afterwards (`pgrep -f "gz sim"`),
stop it with `pkill -f 'gz sim'`: a leftover simulator confuses the next run. `start_sim.sh`
warns you about this.

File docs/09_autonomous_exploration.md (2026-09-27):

# 09 · Autonomous exploration

`frontier_explorer` (`src/rover_control/rover_control/frontier_explorer.py`) turns
"SLAM + Nav2" into a robot that maps an unknown building by itself.

## The idea

A **frontier** is where known free space meets unknown space. Driving to a frontier reveals what
lies behind it. Repeat until no frontiers are left, and the map is complete.

map

## The algorithm (every 1.5 s)

```
1. Wait until: exploration enabled, mode == AUTO, a map exists, TF map→robot exists, Nav2 is up.
2. Detect frontiers on the occupancy grid:
     free     = cells with 0 ≤ value < 25
     unknown  = cells with value −1
     frontier = free cells that touch an unknown cell (4-neighbourhood)
     drop frontier cells closer than `clearance` (0.30 m) to an obstacle
     group them into clusters (8-connected labelling)
     drop clusters shorter than `min_frontier_size` (0.40 m)
     goal of each cluster = its cell closest to the cluster centroid
3. If a goal is active: keep it unless
     – it timed out (90 s), or the robot made no progress for 20 s        → blacklist it
     – the robot is within 0.45 m but the area is still unknown (occluded) → blacklist it
     – the frontier was uncovered on the way                              → pick the next one now
4. Score the candidates:   cost = distance_weight · distance − size_weight · frontier_length
   (skip blacklisted ones and those closer than 0.5 m)
5. Send the cheapest one to Nav2 (navigate_to_pose), facing the unknown.
6. No candidates for 5 checks in a row → the map is complete → drive home → DONE.
```

It is implemented with NumPy and SciPy's `ndimage` (dilation, labelling, distance transform), so
each evaluation takes milliseconds even on large maps.

## Design decisions (and the bugs that led to them)

These were all discovered while testing, and they're typical of real robotics work:

| Problem seen in testing | Fix |
|---|---|
| At start-up the map is nearly empty (a single scan); the explorer found nothing and declared "done" immediately | require `done_confirmations` (5) empty evaluations in a row |
| Nav2 was still starting and **rejected** the first goal; the explorer blacklisted the only frontier | a rejection is retried after 3 s instead of blacklisted |
| A frontier behind the sofa could be approached but never seen; the robot hovered next to it for a minute | the "reached but still unknown → occluded" rule, plus a 20 s no-progress rule |
| When the explorer switched to a better frontier, Nav2 reported the old goal as *aborted*, which looked like a failure | results of superseded goals are ignored |
| Goals hugging walls were hard to reach | the `clearance` filter (distance transform on obstacles) |

## Cooperation with the rest of the system

* **Mode:** it acts only in AUTO (it subscribes to the latched `/robot_mode`). Switching to MANUAL
  makes it forget its goal (the mode manager cancels it).
* **User goals win:** it watches `/navigate_to_pose/_action/status`. Every goal it sends carries a
  UUID it generated itself, so any *other* active goal id means a person (or another program) sent
  a goal. Exploration then pauses: `PAUSED (user goal)`.
* **Enable/disable:** `/explore/enable` (`std_srvs/SetBool`), or `o` on the keyboard.
* **Status:** `/explore/status` (latched), shown in the keyboard status line.
* **Visualisation:** `/explore/frontiers` (MarkerArray): green frontier cells, blue candidate goals,
  red current target.

## Parameters (`rover_bringup/config/control.yaml`)

| Parameter | Default | Effect |
|---|---|---|
| `enabled_on_start` | true | explore as soon as AUTO is selected |
| `planner_period` | 1.5 s | how often to re-evaluate |
| `min_frontier_size` | 0.40 m | ignore tiny gaps |
| `clearance` | 0.30 m | keep goals away from walls |
| `distance_weight` / `size_weight` | 1.0 / 0.6 | nearby vs. big frontiers |
| `goal_timeout` / `stuck_timeout` | 90 / 20 s | when to give up on a goal |
| `reached_radius` | 0.45 m | "close enough; if still unknown, it's occluded" |
| `done_confirmations` | 5 | empty checks before declaring completion |
| `return_home` | true | drive back to the start when done |

**Experiment:** set `size_weight: 0.0` (always the nearest frontier) or `distance_weight: 0.2`
(prefer big frontiers), then compare the total exploration time. That is [Lab 7](10_hands_on_labs.md#lab-7--tune-the-explorer).

## Measured result

In the default world, starting from the origin in AUTO: **131 m² mapped in about 4.4 min of
simulated time**. The explorer skipped two occluded spots, returned home and reported `DONE`.
Localization error at the end: about 1 cm.

## Where to go next

* **Information gain** instead of frontier length: estimate how many unknown cells would become
  visible from a goal (ray casting) and pick the most informative, not just the biggest.
* **Travel cost from the planner**: use Nav2's `compute_path_to_pose` path length instead of
  straight-line distance (walls make straight lines misleading).
* **Multi-robot exploration**: robots share the map and avoid picking the same frontier.

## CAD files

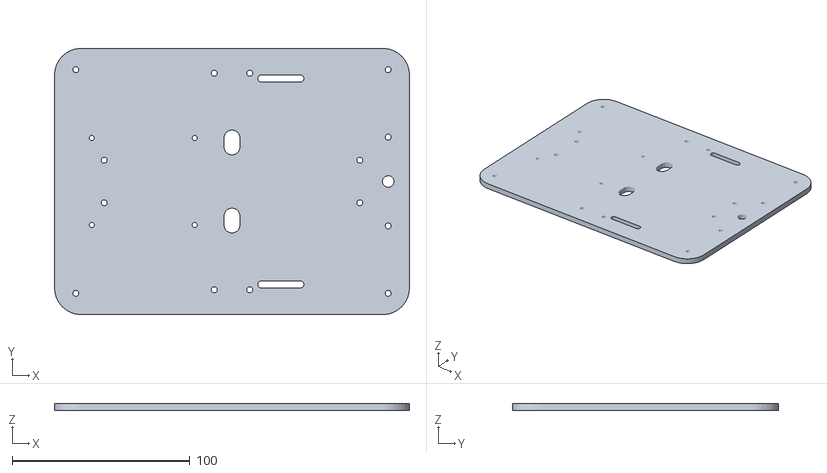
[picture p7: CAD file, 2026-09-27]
hardware/stl/base_plate.stl
200.0 x 150.0 x 4.00

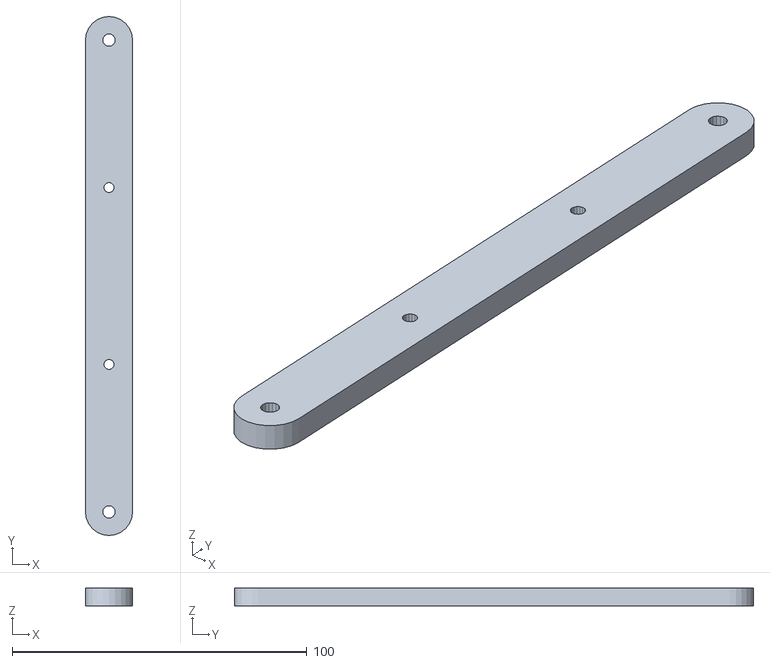
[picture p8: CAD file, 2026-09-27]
hardware/stl/rover4/front_beam.stl
16.0 x 176.0 x 6.00

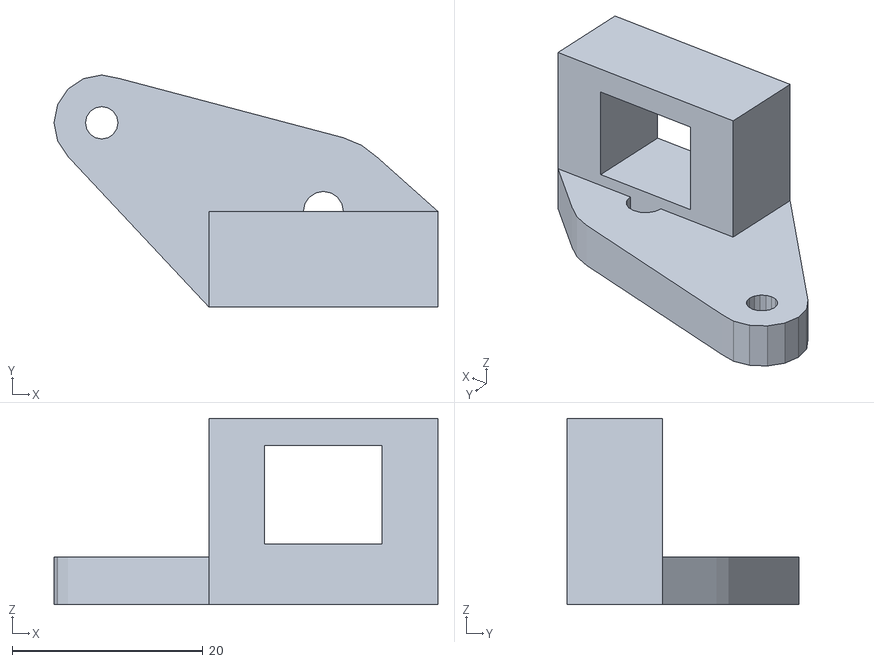
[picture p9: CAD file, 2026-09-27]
hardware/stl/rover4/knuckle_left.stl
40.2 x 24.3 x 19.5

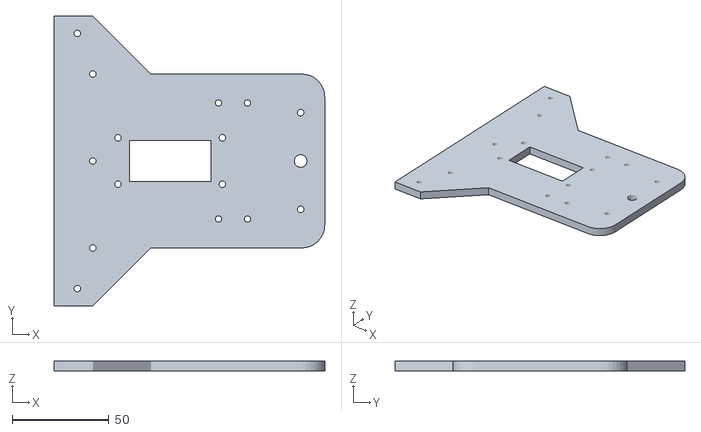
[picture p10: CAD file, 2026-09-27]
src/rover_description/meshes/rover4_base_front.stl
140.0 x 150.0 x 5.00

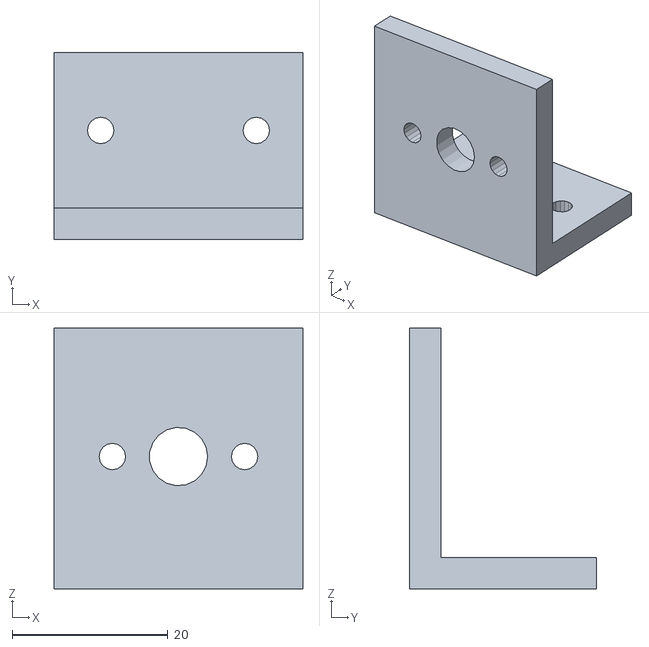
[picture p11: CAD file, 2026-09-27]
hardware/stl/motor_bracket.stl
32.0 x 24.0 x 33.5

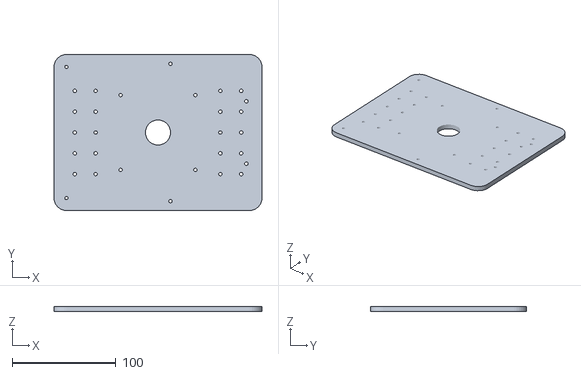
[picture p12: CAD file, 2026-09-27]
hardware/stl/rover4/top_plate.stl
200.0 x 150.0 x 5.00

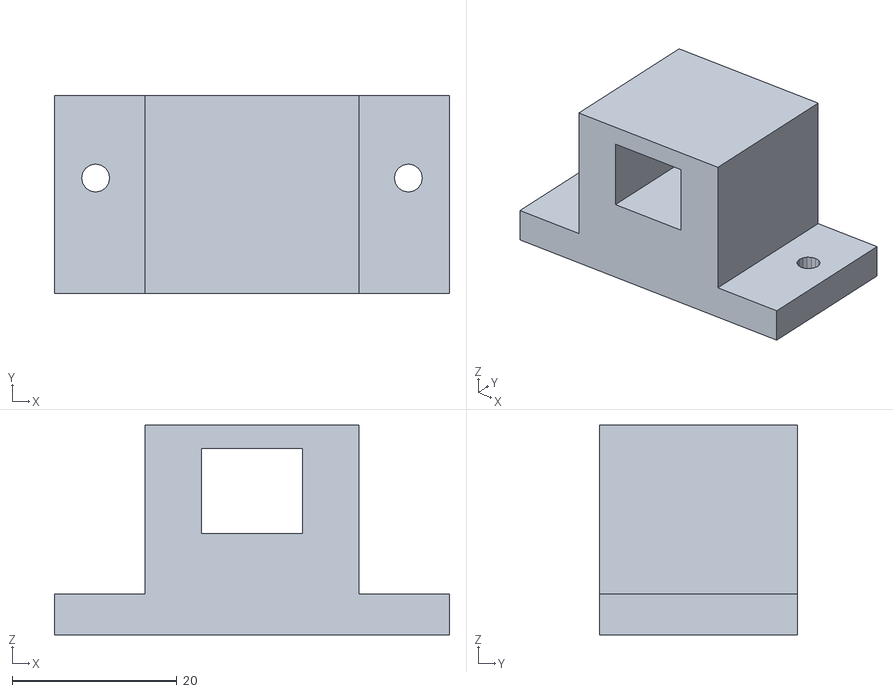
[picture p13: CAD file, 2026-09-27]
hardware/stl/rover4/rear_motor_clamp.stl
48.0 x 24.0 x 25.5

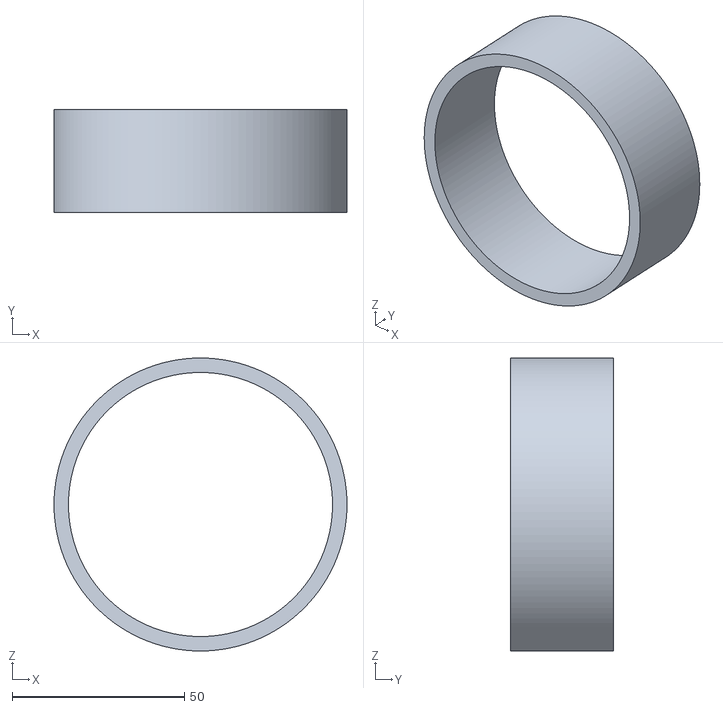
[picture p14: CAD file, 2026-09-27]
src/rover_description/meshes/rover4_tire_tpu.stl
85.0 x 30.0 x 85.0

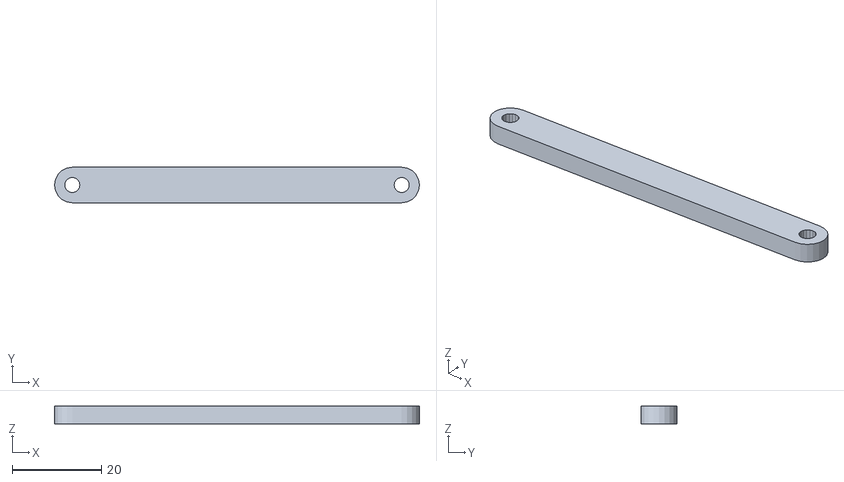
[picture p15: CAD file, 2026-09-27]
hardware/stl/rover4/tie_rod.stl
82.0 x 8.00 x 4.00

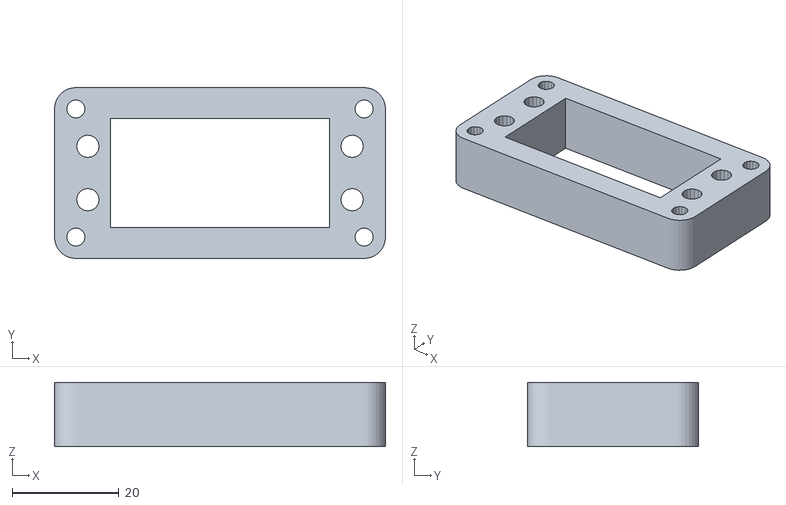
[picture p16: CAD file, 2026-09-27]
src/rover_description/meshes/rover4_servo_mount.stl
62.0 x 32.0 x 12.0

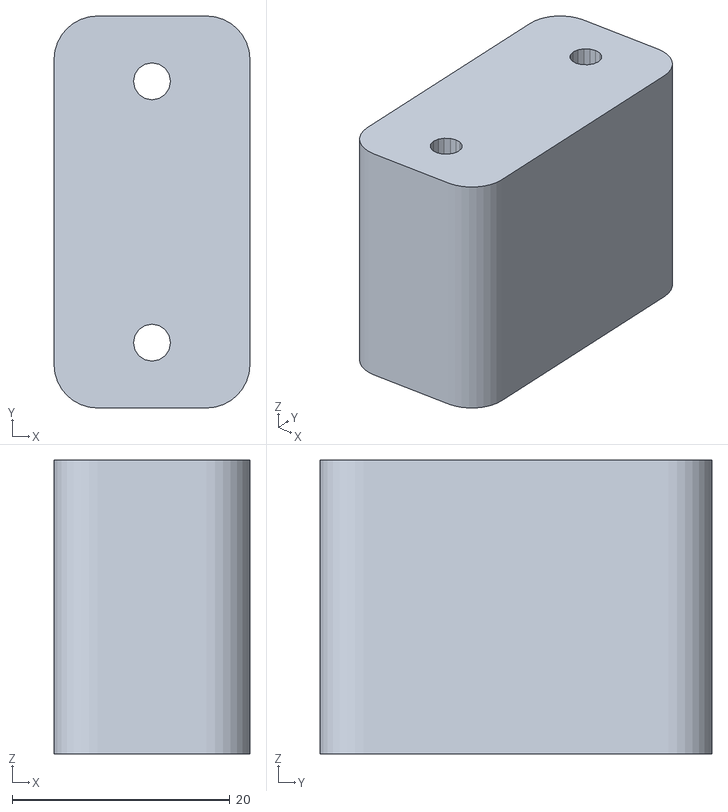
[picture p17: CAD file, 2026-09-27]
hardware/stl/caster_spacer.stl
18.0 x 36.0 x 27.0

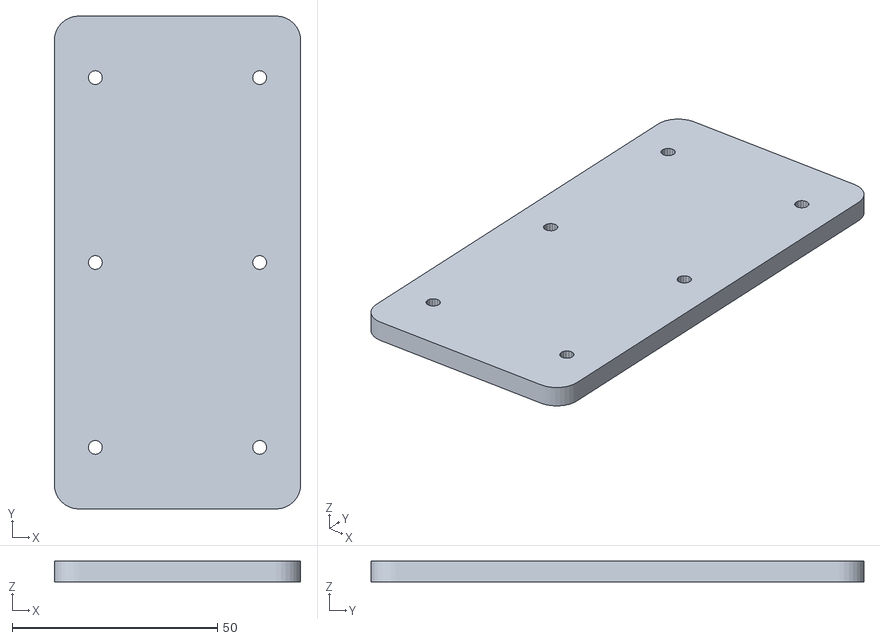
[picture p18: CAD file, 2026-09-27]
src/rover_description/meshes/rover4_splice_plate.stl
60.0 x 120.0 x 5.00

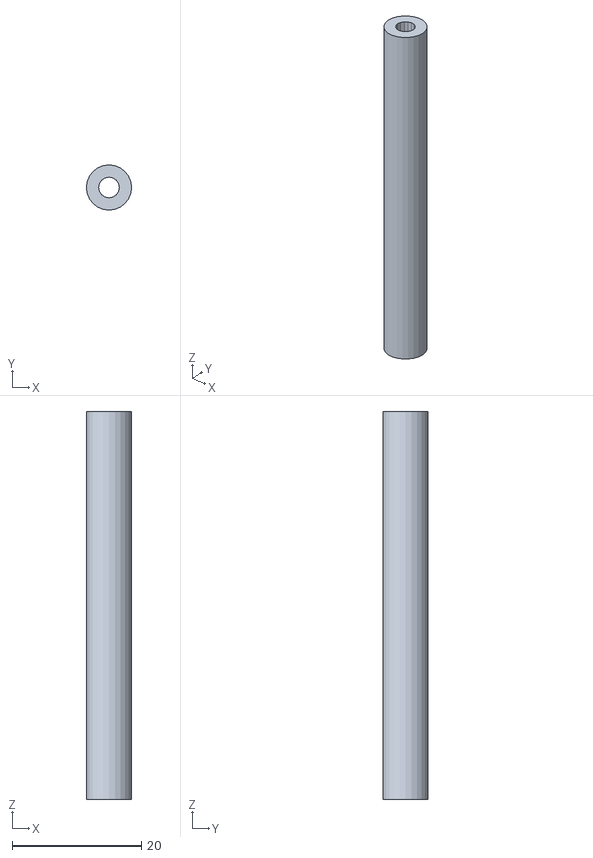
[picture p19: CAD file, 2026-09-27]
hardware/stl/rover4/standoff.stl
7.00 x 7.00 x 60.0

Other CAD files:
src/rover_description/meshes/rover4_front_beam.stl
src/rover_description/meshes/rover4_knuckle_right.stl
hardware/stl/rover4/base_front.stl
src/rover_description/meshes/rover4_knuckle_left.stl
hardware/stl/rover4/servo_mount.stl
hardware/stl/camera_riser.stl
hardware/stl/lidar_riser.stl
hardware/stl/rover4/base_rear.stl
hardware/stl/rover4/camera_riser.stl
hardware/stl/rover4/knuckle_right.stl
hardware/stl/rover4/lidar_riser.stl
hardware/stl/rover4/splice_plate.stl
hardware/stl/rover4/tire_tpu.stl
hardware/stl/rover4/wheel_hub.stl
hardware/stl/standoff.stl
hardware/stl/tire_tpu.stl
hardware/stl/top_plate.stl
hardware/stl/wheel_hub.stl
src/rover_description/meshes/camera_riser.stl
src/rover_description/meshes/lidar_riser.stl
src/rover_description/meshes/rover4_base_rear.stl
src/rover_description/meshes/rover4_camera_riser.stl
src/rover_description/meshes/rover4_lidar_riser.stl
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

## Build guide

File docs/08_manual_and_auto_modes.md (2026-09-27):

# 08 · Manual and autonomous modes

## The design: one gate to the wheels

```
teleop_keyboard ──/cmd_vel_teleop──┐
                                   ├──► mode_manager ──/cmd_vel──► robot
Nav2 ──────────────/cmd_vel_nav────┘         ▲
                                  /mode_request, /set_autonomous
```

`mode_manager` (`src/rover_control/rover_control/mode_manager.py`) is a **velocity
multiplexer**, the only node allowed to publish `/cmd_vel`:

| Mode | Forwards | Ignores |
|---|---|---|
| `MANUAL` | `/cmd_vel_teleop` | `/cmd_vel_nav` |
| `AUTO` | `/cmd_vel_nav` | `/cmd_vel_teleop` |

Why this design? Without a single gate, the keyboard and Nav2 would fight over the wheels, 20 times
a second each. With a gate:

* only one source ever reaches the robot,
* switching modes is a single state change,
* safety rules live in exactly one place.

## Safety behaviours

| Behaviour | How |
|---|---|
| **Dead-man** | the gate publishes a steady 20 Hz stream. If the selected source has been silent for `teleop_timeout` / `nav_timeout` (0.5 s), the stream is **zero**. A crashed node or a lost message can never leave the robot driving. |
| **No stale commands** | on every mode switch the last stored commands are discarded and a zero is sent. |
| **Clean hand-over** | switching AUTO → MANUAL **cancels every Nav2 goal**, so the robot never resumes an old goal by surprise. |
| **Hard speed clamp** | `max_linear` / `max_angular` apply in both modes; NaN or infinite values become 0. |
| **Take-over** | in the keyboard node, any drive key pressed in AUTO requests MANUAL first. |

How can the gate cancel goals it didn't send? Every ROS 2 action server offers a
`<action>/_action/cancel_goal` service. A request with an all-zero goal id and time stamp means
"cancel all goals". The mode manager calls this for `navigate_to_pose`,
`navigate_through_poses` and `follow_waypoints`.

## Interfaces

| Name | Kind | Use |
|---|---|---|
| `/robot_mode` | topic `std_msgs/String`, **latched** | current mode; late subscribers still get it |
| `/mode_request` | topic `std_msgs/String` | `"manual"`, `"auto"` or `"toggle"` |
| `/set_autonomous` | service `std_srvs/SetBool` | `true` = AUTO |

A "latched" topic uses the QoS `durability: TRANSIENT_LOCAL`: the publisher keeps the last message
and hands it to anyone who subscribes later. Subscribers must use the same QoS.

## The keyboard node

`teleop_keyboard.py` puts the terminal into *cbreak* mode (keys arrive immediately, without Enter)
and polls it with `select()` 20 times a second.

A terminal cannot report key **releases**. "Hold to drive" is therefore emulated: while a key is
held, the terminal repeats it about 30 times a second, and motion continues until no repeat has
arrived for `key_timeout` (0.6 s, longer than the typical 0.5 s repeat delay). For classic latched
behaviour (press once, keep going) use:

```bash
ros2 run rover_control teleop_keyboard --ros-args -p hold_to_drive:=false
```

Other parameters: `linear_speed`, `angular_speed`, `accel_linear`, `accel_angular` (a smooth ramp
up; stopping is immediate), `take_over_auto`.

## Parameters (`rover_bringup/config/control.yaml`)

```yaml
mode_manager:
  ros__parameters:
    initial_mode: manual
    teleop_timeout: 0.5
    nav_timeout: 0.5
    max_linear: 0.5
    max_angular: 2.5
    cancel_nav_on_manual: true
```

## Ideas to extend it

* Add a third mode, `ASSISTED`: keyboard commands filtered by the collision monitor. Nav2's
  `assisted_teleop` behaviour already exists.
* Add a gamepad: `teleop_twist_joy` remapped to `/cmd_vel_teleop`, with a button that publishes to `/mode_request`.
* Add an `ESTOP` mode that also latches until explicitly reset.

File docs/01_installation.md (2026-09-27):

# 01 · Installation

Target platform: **Ubuntu 24.04 (Noble) + ROS 2 Jazzy + Gazebo Harmonic**. These three are an
official matching set; other combinations (for example Humble + Gazebo Classic) will not work
without changes.

> **Not on Ubuntu 24.04?** Use a virtual machine or a dual boot. WSL2 on Windows 11 can run it
> (with WSLg for the GUI), but 3D rendering is slow; use `headless:=true` there.

## 1. Install ROS 2 Jazzy

Follow the official guide: <https://docs.ros.org/en/jazzy/Installation/Ubuntu-Install-Debs.html>.
It comes down to the following steps (check the guide for the latest version):

```bash
# locale + repositories
sudo apt update && sudo apt install -y software-properties-common curl
sudo add-apt-repository universe
# the ROS apt source (the official guide installs the ros2-apt-source package)
export ROS_APT_SOURCE_VERSION=$(curl -s https://api.github.com/repos/ros-infrastructure/ros-apt-source/releases/latest | grep -F "tag_name" | awk -F\" '{print $4}')
curl -L -o /tmp/ros2-apt-source.deb "https://github.com/ros-infrastructure/ros-apt-source/releases/download/${ROS_APT_SOURCE_VERSION}/ros2-apt-source_${ROS_APT_SOURCE_VERSION}.$(. /etc/os-release && echo $VERSION_CODENAME)_all.deb"
sudo dpkg -i /tmp/ros2-apt-source.deb
sudo apt update && sudo apt upgrade -y
sudo apt install -y ros-jazzy-desktop ros-dev-tools
```

Check that it works:

```bash
source /opt/ros/jazzy/setup.bash
ros2 run demo_nodes_cpp talker     # Ctrl-C to stop
```

## 2. Install the project's dependencies

```bash
sudo apt install -y \
  ros-jazzy-ros-gz \
  ros-jazzy-navigation2 ros-jazzy-nav2-bringup \
  ros-jazzy-slam-toolbox \
  ros-jazzy-robot-localization \
  ros-jazzy-xacro ros-jazzy-joint-state-publisher-gui \
  python3-scipy
```

`ros-jazzy-ros-gz` pulls in **Gazebo Harmonic**. Check it with `gz sim --versions` (expect 8.x).

## 3. Get and build the workspace

```bash
git clone https://github.com/osama13robot/ros2-autonomous-rover.git ~/ros2-autonomous-rover
cd ~/ros2-autonomous-rover
source /opt/ros/jazzy/setup.bash
rosdep update && rosdep install --from-paths src --ignore-src -y   # catches anything missing
colcon build --symlink-install
```

`--symlink-install` links Python files and configs instead of copying them. You can then edit a
`.yaml`, `.py` or launch file and simply restart the program, with no rebuild. You only need to
rebuild after adding new files or changing `setup.py` / `CMakeLists.txt`.

## 4. Source the workspace

Every new terminal needs:

```bash
source /opt/ros/jazzy/setup.bash
source ~/ros2-autonomous-rover/install/setup.bash
```

To make this automatic, add both lines to the end of `~/.bashrc`.

## 5. Verify

```bash
colcon test --packages-select rover_control && colcon test-result --verbose
# → Summary: 4 tests, 0 errors, 0 failures, 0 skipped

ros2 launch rover_description display.launch.py
# → RViz shows the robot; move the wheel sliders
```

You're ready for the [Quick start](02_quick_start.md).

## Optional: the 3D-printable parts

The STL files are already in `hardware/stl/`. To regenerate them after changing dimensions you only
need Python 3 with numpy and PyYAML, which ROS 2 already installs:

```bash
python3 hardware/generate_parts.py --check
```

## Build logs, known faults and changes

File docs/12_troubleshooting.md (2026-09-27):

# 12 · Troubleshooting

## Start-up

| Symptom | Cause and fix |
|---|---|
| `Package 'rover_bringup' not found` | the workspace isn't sourced: `source install/setup.bash` |
| `colcon build` fails with a missing package | run `rosdep install --from-paths src --ignore-src -y` |
| The keyboard window doesn't open | `start_sim.sh` needs `gnome-terminal`; otherwise run `ros2 run rover_control teleop_keyboard` yourself |
| `teleop_keyboard needs an interactive terminal` | it can't run inside `ros2 launch` or a pipe; use a normal terminal |
| `WARNING: a Gazebo server is already running` | a previous run didn't shut down cleanly: `pkill -f 'gz sim'` |
| The robot behaves strangely, sensors jump around, "ghost" obstacles | **two simulators are running at once** and both publish the same topics. Stop everything: `pkill -f 'gz sim'`, then check `pgrep -af "gz sim"` |
| Gazebo shows the robot but RViz shows nothing | RViz Fixed Frame is `map`, and `map` exists only once SLAM has started (a few seconds) |

## Performance

| Symptom | Fix |
|---|---|
| Gazebo real-time factor well below 1.0 | `headless:=true`; close other programs; see [05 Simulation](05_simulation.md#performance-tips) |
| `Control loop missed its desired rate` warnings | normal on slow machines; reduce MPPI `batch_size` if the robot drives badly |
| `collision_monitor: … timestamps differ … Ignoring the source` followed by `Robot to stop` | the camera data arrived more than `source_timeout` late, so the robot pauses for safety. Normal on a slow simulator; raise `source_timeout` or reduce the simulator load |
| `map_saver` fails with a timeout | the simulator is slow; `save_map.sh` already uses 20 s; pass `-p save_map_timeout:=60.0` if needed |

## Driving and navigation

| Symptom | Cause and fix |
|---|---|
| The keyboard does nothing | the robot is in AUTO (status line shows `[AUTO]`). Press `1`, or any drive key to take over |
| Goals from RViz are ignored | the robot is in MANUAL. Press `2` first |
| AUTO, but the robot doesn't move | check `ros2 topic echo /explore/status`. `WAITING for Nav2`: Nav2 is still starting (about 10 s). `DONE`: nothing left to explore |
| The robot stops and starts a lot near obstacles | the collision monitor is being cautious; lower `time_before_collision` |
| `Start occupied` / `Failed to create plan` | the robot or the goal is inside an inflated obstacle. Pick goals further from walls, or reduce `inflation_radius` |
| `Failed to make progress` then spins or backs up | recoveries at work; normal occasionally. Often, the goal is in a narrow gap |
| The explorer leaves grey patches | areas it cannot see into (behind furniture) are skipped on purpose; see [09](09_autonomous_exploration.md) |
| AMCL: the robot is in the wrong place on the map | use *2D Pose Estimate* in RViz to give the right start pose |
| `ros2 action send_goal` prints nothing, and the log says `Failed to send goal response … (timeout)` | a start-up race between a brand-new command-line client and the action server; just send the goal again |
| rover4 hesitates or reverses near walls and doorways | normal for a car-like robot: it needs room to turn (radius ≈ 0.4 m) and makes multi-point turns |

## Useful diagnostic commands

```bash
ros2 topic echo /robot_mode                    # MANUAL / AUTO
ros2 topic echo /explore/status                # what the explorer is doing
ros2 lifecycle get /bt_navigator               # should be "active [3]"
ros2 topic hz /scan                            # are sensors publishing?
ros2 run tf2_ros tf2_echo map base_footprint   # where does the robot think it is?
ros2 run tf2_tools view_frames                 # full TF tree as a PDF
ros2 doctor --report                           # general ROS health check
gz topic -l                                    # Gazebo-side topics
```

When you ask for help (an issue, a forum), include: the command you ran, the **first** error in the
output (not the last), and the output of `ros2 doctor --report`.

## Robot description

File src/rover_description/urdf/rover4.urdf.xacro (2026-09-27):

<?xml version="1.0"?>
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
<robot name="rover4" xmlns:xacro="http://www.ros.org/wiki/xacro">

  <xacro:arg name="sim_gazebo" default="true"/>
  <xacro:arg name="use_meshes" default="true"/>   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

  <xacro:include filename="$(find rover_description)/urdf/inertial_macros.xacro"/>
  <xacro:include filename="$(find rover_description)/urdf/materials.xacro"/>

  <xacro:property name="d" value="${xacro.load_yaml('$(find rover_description)/config/dimensions_rover4.yaml')}"/>
  <xacro:property name="mesh" value="package://rover_description/meshes/rover4_"/>
  <xacro:property name="mm" value="0.001 0.001 0.001"/>

  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
  <xacro:property name="c" value="${d['chassis']}"/>
  <xacro:property name="R" value="${d['wheel']['radius']}"/>
  <xacro:property name="WW" value="${d['wheel']['width']}"/>
  <xacro:property name="L" value="${d['axles']['wheelbase']}"/>
  <xacro:property name="track" value="${d['axles']['track']}"/>
  <xacro:property name="kingpin_y" value="${d['steering']['kingpin_y']}"/>
  <xacro:property name="steer_limit" value="${d['steering']['limit']}"/>
  <xacro:property name="T" value="${c['plate_thickness']}"/>
  <xacro:property name="z_low_bot" value="${c['lower_plate_z'] - R}"/>
  <xacro:property name="z_low_top" value="${z_low_bot + T}"/>
  <xacro:property name="z_up_bot" value="${z_low_top + c['deck_spacing']}"/>
  <xacro:property name="z_up_top" value="${z_up_bot + T}"/>
  <xacro:property name="mo" value="${d['motor']}"/>
  <xacro:property name="lidar" value="${d['lidar']}"/>
  <xacro:property name="cam" value="${d['camera']}"/>

  <xacro:macro name="mesh_visual" params="name material rpy:='0 0 0'">
    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
  </xacro:macro>

  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
  <link name="base_footprint"/>

  <joint name="base_joint" type="fixed">
    <parent link="base_footprint"/>
    <child link="base_link"/>
    <origin xyz="0 0 ${R}"/>
  </joint>

  <link name="base_link">
    <xacro:mesh_visual name="base_rear" material="printed_orange"/>
    <xacro:mesh_visual name="base_front" material="printed_orange"/>
    <xacro:mesh_visual name="splice_plate" material="printed_grey"/>
    <xacro:mesh_visual name="top_plate" material="printed_orange"/>
    <xacro:mesh_visual name="front_beam" material="printed_grey"/>
    <xacro:mesh_visual name="servo_mount" material="printed_grey"/>
    <xacro:mesh_visual name="lidar_riser" material="printed_grey"/>
    <xacro:mesh_visual name="camera_riser" material="printed_grey"/>
    <xacro:mesh_visual name="rear_motor_clamp" material="printed_grey"/>
    <xacro:mesh_visual name="rear_motor_clamp" material="printed_grey" rpy="0 0 ${pi}"/>

    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
    <xacro:macro name="rear_motor" params="side">
      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
    </xacro:macro>
    <xacro:rear_motor side="1"/>
    <xacro:rear_motor side="-1"/>

    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
    <xacro:macro name="standoff" params="x y">
      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
    </xacro:macro>
    <xacro:standoff x="0.012" y="0.063"/>
    <xacro:standoff x="0.012" y="-0.063"/>
    <xacro:standoff x="0.112" y="0.066"/>
    <xacro:standoff x="0.112" y="-0.066"/>
    <xacro:standoff x="0.185" y="0.030"/>
    <xacro:standoff x="0.185" y="-0.030"/>

    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

    <xacro:box_inertia m="${c['mass_lower'] + c['mass_upper'] + 2*mo['mass']}" x="${c['front_x'] - c['rear_x']}" y="${c['width']}" z="${z_up_top - z_low_bot}">
      <origin xyz="${(c['rear_x'] + c['front_x'])/2 - 0.02} 0 ${z_low_top + 0.015}"/>
    </xacro:box_inertia>
  </link>

  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
  <xacro:macro name="wheel_link" params="name side">
    <link name="${name}_wheel_link">
      <xacro:mesh_visual name="wheel_hub" material="printed_grey" rpy="0 0 ${0 if side > 0 else pi}"/>
      <xacro:mesh_visual name="tire_tpu" material="rubber" rpy="0 0 ${0 if side > 0 else pi}"/>
      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
      <xacro:cylinder_inertia m="${d['wheel']['mass']}" r="${R}" h="${WW}">
        <origin rpy="${pi/2} 0 0"/>
      </xacro:cylinder_inertia>
    </link>
    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
  </xacro:macro>

  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
  <xacro:macro name="rear_wheel" params="prefix side">
    <xacro:wheel_link name="rear_${prefix}" side="${side}"/>
    <joint name="rear_${prefix}_wheel_joint" type="continuous">
      <parent link="base_link"/>
      <child link="rear_${prefix}_wheel_link"/>
      <origin xyz="0 ${side*track/2} 0"/>
      <axis xyz="0 1 0"/>
      <dynamics damping="0.01"/>
    </joint>
  </xacro:macro>
  <xacro:rear_wheel prefix="left" side="1"/>
  <xacro:rear_wheel prefix="right" side="-1"/>

  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
  <xacro:macro name="front_corner" params="prefix side">
    <link name="front_${prefix}_steering_link">
      <xacro:mesh_visual name="knuckle_${prefix}" material="printed_grey"/>
      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
      <xacro:box_inertia m="0.05" x="0.03" y="0.03" z="0.02">
        <origin xyz="0 0 0"/>
      </xacro:box_inertia>
    </link>
    <joint name="front_${prefix}_steering_joint" type="revolute">
      <parent link="base_link"/>
      <child link="front_${prefix}_steering_link"/>
      <origin xyz="${L} ${side*kingpin_y} 0"/>
      <axis xyz="0 0 1"/>
      <limit lower="${-steer_limit}" upper="${steer_limit}" effort="5.0" velocity="4.0"/>
      <dynamics damping="0.05"/>
    </joint>

    <xacro:wheel_link name="front_${prefix}" side="${side}"/>
    <joint name="front_${prefix}_wheel_joint" type="continuous">
      <parent link="front_${prefix}_steering_link"/>
      <child link="front_${prefix}_wheel_link"/>
      <origin xyz="0 ${side*(track/2 - kingpin_y)} 0"/>
      <axis xyz="0 1 0"/>
      <dynamics damping="0.01"/>
    </joint>
  </xacro:macro>
  <xacro:front_corner prefix="left" side="1"/>
  <xacro:front_corner prefix="right" side="-1"/>

  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
  <link name="lidar_link">
    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
    <xacro:box_inertia m="${lidar['mass']}" x="${lidar['size']}" y="${lidar['size']}" z="${lidar['height']}">
      <origin xyz="0 0 ${-lidar['scan_plane'] + lidar['height']/2}"/>
    </xacro:box_inertia>
  </link>
  <joint name="lidar_joint" type="fixed">
    <parent link="base_link"/>
    <child link="lidar_link"/>
    <origin xyz="${lidar['x']} 0 ${z_up_top + lidar['riser_height'] + lidar['scan_plane']}"/>
  </joint>

  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
  <link name="camera_link">
    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
    <xacro:box_inertia m="${cam['mass']}" x="${cam['depth']}" y="${cam['width']}" z="${cam['height']}">
      <origin xyz="0 0 0"/>
    </xacro:box_inertia>
  </link>
  <joint name="camera_joint" type="fixed">
    <parent link="base_link"/>
    <child link="camera_link"/>
    <origin xyz="${cam['x']} 0 ${z_low_top + cam['riser_height'] + cam['height']/2}" rpy="0 ${cam['pitch']} 0"/>
  </joint>

  <link name="camera_optical_link"/>
  <joint name="camera_optical_joint" type="fixed">
    <parent link="camera_link"/>
    <child link="camera_optical_link"/>
    <origin rpy="${-pi/2} 0 ${-pi/2}"/>
  </joint>

  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
  <link name="imu_link"/>
  <joint name="imu_joint" type="fixed">
    <parent link="camera_link"/>
    <child link="imu_link"/>
    <origin xyz="-0.006 0.0 0.0"/>
  </joint>

  <xacro:if value="$(arg sim_gazebo)">
    <xacro:include filename="$(find rover_description)/urdf/rover4.gazebo.xacro"/>
  </xacro:if>

</robot>

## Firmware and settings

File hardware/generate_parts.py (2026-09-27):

#!/usr/bin/env python3
"""
Parametric generator for the 3D-printable parts of the rover.

Only needs Python 3 + numpy + PyYAML (both ship with ROS 2). No CAD program is
required: every part is a union of 2.5D extrusions (polygon + holes), which is
triangulated with ear clipping and written as a binary STL.

Dimensions come from src/rover_description/config/dimensions.yaml, the
same file the URDF uses, so the simulated robot always matches the printed one.

Usage:
    python3 generate_parts.py                  # both robots
    python3 generate_parts.py --robot rover4   # only the 4WD Ackermann robot
    python3 generate_parts.py --check          # also verifies every mesh is watertight

Outputs (millimetres, already in print orientation, flat side down):
    stl/*.stl                               -> rover (2WD) parts: slice and print these
    stl/rover4/*.stl                        -> rover4 (4WD Ackermann) parts
    ../src/rover_description/meshes          -> copies used as visuals in the simulator
"""
import argparse
import math
import shutil
import struct
from pathlib import Path

import numpy as np
import yaml

HERE = Path(__file__).resolve().parent
DIMS_FILE = HERE.parent / 'src/rover_description/config/dimensions.yaml'
DIMS_FILE_ROVER4 = HERE.parent / 'src/rover_description/config/dimensions_rover4.yaml'
STL_DIR = HERE / 'stl'
MESH_DIR = HERE.parent / 'src/rover_description/meshes'

# Parts that are also used as visual meshes in the URDF
VISUAL_PARTS = ['base_plate', 'top_plate', 'wheel_hub', 'tire_tpu', 'motor_bracket',
                'caster_spacer', 'lidar_riser', 'camera_riser']

M3 = 3.4        # clearance hole for M3 screws
M25 = 2.9       # clearance hole for M2.5 screws (Raspberry Pi)
QUARTER = 6.6   # clearance hole for 1/4"-20 camera tripod screw


# ---------------------------------------------------------------------------
# 2D shapes (lists of (x, y) tuples, mm)
# ---------------------------------------------------------------------------
def circle(cx, cy, r, n=None):
    n = n or max(16, int(2 * math.pi * r / 1.2))
    return [(cx + r * math.cos(2 * math.pi * i / n), cy + r * math.sin(2 * math.pi * i / n))
            for i in range(n)]


def rounded_rect(cx, cy, w, h, r, n_corner=8):
    r = min(r, w / 2 - 1e-3, h / 2 - 1e-3)
    pts = []
    corners = [(cx + w / 2 - r, cy + h / 2 - r, 0.0), (cx - w / 2 + r, cy + h / 2 - r, 90.0),
               (cx - w / 2 + r, cy - h / 2 + r, 180.0), (cx + w / 2 - r, cy - h / 2 + r, 270.0)]
    for (ox, oy, a0) in corners:
        for i in range(n_corner + 1):
            a = math.radians(a0 + 90.0 * i / n_corner)
            pts.append((ox + r * math.cos(a), oy + r * math.sin(a)))
    return pts


def rect(cx, cy, w, h):
    return [(cx - w / 2, cy - h / 2), (cx + w / 2, cy - h / 2),
            (cx + w / 2, cy + h / 2), (cx - w / 2, cy + h / 2)]


def slot(cx, cy, length, width, angle_deg=0.0, n=10):
    """Stadium-shaped slot, `length` measured tip to tip."""
    r = width / 2
    half = max(length / 2 - r, 0.0)
    pts = []
    for sign, a0 in ((1, -90.0), (-1, 90.0)):
        for i in range(n + 1):
            a = math.radians(a0 + 180.0 * i / n)
            pts.append((sign * half + r * math.cos(a), r * math.sin(a)))
    c, s = math.cos(math.radians(angle_deg)), math.sin(math.radians(angle_deg))
    return [(cx + x * c - y * s, cy + x * s + y * c) for x, y in pts]


def d_shape(cx, cy, dia, flat_depth, n=32):
    """D-shaft hole: circle with a flat on the +y side."""
    r = dia / 2
    y_flat = r - flat_depth
    a_flat = math.asin(y_flat / r)
    a0, a1 = math.pi - a_flat, 2 * math.pi + a_flat
    pts = [(cx + r * math.cos(a0 + (a1 - a0) * i / n), cy + r * math.sin(a0 + (a1 - a0) * i / n))
           for i in range(n + 1)]
    return pts


# ---------------------------------------------------------------------------
# Triangulation: ear clipping with hole bridging
# ---------------------------------------------------------------------------
def _area(poly):
    a = 0.0
    for i in range(len(poly)):
        x1, y1 = poly[i]
        x2, y2 = poly[(i + 1) % len(poly)]
        a += x1 * y2 - x2 * y1
    return a / 2


def _point_in_poly(pt, poly):
    x, y = pt
    inside = False
    n = len(poly)
    for i in range(n):
        x1, y1 = poly[i]
        x2, y2 = poly[(i + 1) % n]
        if (y1 > y) != (y2 > y):
            if x < x1 + (y - y1) * (x2 - x1) / (y2 - y1):
                inside = not inside
    return inside


def _segments_cross(p, q, a, b):
    """Vectorised proper intersection of segment pq with segments a[i]b[i]."""
    def orient(p1, p2, p3):
        return (p2[..., 0] - p1[..., 0]) * (p3[..., 1] - p1[..., 1]) - \
               (p2[..., 1] - p1[..., 1]) * (p3[..., 0] - p1[..., 0])
    p = np.broadcast_to(p, a.shape)
    q = np.broadcast_to(q, a.shape)
    d1, d2 = orient(p, q, a), orient(p, q, b)
    d3, d4 = orient(a, b, p), orient(a, b, q)
    eps = 1e-9
    return (((d1 > eps) & (d2 < -eps)) | ((d1 < -eps) & (d2 > eps))) & \
           (((d3 > eps) & (d4 < -eps)) | ((d3 < -eps) & (d4 > eps)))


def _edges(poly):
    a = np.asarray(poly, dtype=float)
    return a, np.roll(a, -1, axis=0)


def _bridge(poly, hole, others):
    """Merge `hole` (CW) into `poly` (CCW) through the shortest visible bridge."""
    mi = max(range(len(hole)), key=lambda i: (hole[i][0], hole[i][1]))
    m = np.array(hole[mi])
    all_edges = [_edges(poly), _edges(hole)] + [_edges(h) for h in others]
    ea = np.concatenate([e[0] for e in all_edges])
    eb = np.concatenate([e[1] for e in all_edges])
    order = sorted(range(len(poly)), key=lambda i: (poly[i][0] - m[0]) ** 2 + (poly[i][1] - m[1]) ** 2)
    for pi in order:
        p = np.array(poly[pi])
        if _segments_cross(m, p, ea, eb).any():
            continue
        # reject bridges that graze a vertex (collinear touching is not a proper crossing)
        d = p - m
        rel = ea - m
        tpar = rel @ d / (d @ d)
        dist = np.abs(rel[:, 0] * d[1] - rel[:, 1] * d[0]) / math.sqrt(d @ d)
        if ((tpar > 1e-9) & (tpar < 1 - 1e-9) & (dist < 1e-7)).any():
            continue
        mid = tuple((m + p) / 2)
        if not _point_in_poly(mid, poly) or _point_in_poly(mid, hole) or \
                any(_point_in_poly(mid, h) for h in others):
            continue
        return poly[:pi + 1] + hole[mi:] + hole[:mi + 1] + poly[pi:]
    raise RuntimeError('could not bridge hole')


def triangulate(outer, holes=()):
    """Triangulate a polygon with holes. Aligned holes can create degenerate (collinear) bridges
    that stall ear clipping; in that case retry on a slightly rotated copy and rotate back."""
    for deg in (0.0, 0.37, 1.13, 2.71):
        c, s_ = math.cos(math.radians(deg)), math.sin(math.radians(deg))
        rot = lambda poly: [(x * c - y * s_, x * s_ + y * c) for x, y in poly]
        try:
            pts, tris = _triangulate(rot(outer), [rot(h) for h in holes])
        except RuntimeError:
            continue
        back = np.column_stack([pts[:, 0] * c + pts[:, 1] * s_, -pts[:, 0] * s_ + pts[:, 1] * c])
        return back, tris
    raise RuntimeError('triangulation failed')


def _triangulate(outer, holes=()):
    outer = list(outer) if _area(outer) > 0 else list(reversed(outer))
    holes = [list(h) if _area(h) < 0 else list(reversed(h)) for h in holes]
    poly = outer
    remaining = sorted(holes, key=lambda h: -max(p[0] for p in h))
    while remaining:
        h = remaining.pop(0)
        poly = _bridge(poly, h, remaining)

    pts = np.asarray(poly, dtype=float)
    idx = list(range(len(pts)))
    tris = []
    guard = 0
    i = 0
    while len(idx) > 3:
        guard += 1
        if guard > 50 * len(pts) + 1000:
            raise RuntimeError('ear clipping failed')
        n = len(idx)
        ia, ib, ic = idx[(i - 1) % n], idx[i % n], idx[(i + 1) % n]
        a, b, c = pts[ia], pts[ib], pts[ic]
        cross = (b[0] - a[0]) * (c[1] - a[1]) - (b[1] - a[1]) * (c[0] - a[0])
        if abs(cross) < 1e-12 and np.allclose(a, c):
            # zero-area spike from a bridge; drop the tip
            idx.pop(i % n)
            continue
        is_ear = cross > 1e-12
        if is_ear:
            others = pts[idx]
            v0, v1, v2 = c - a, b - a, others - a
            d00, d01, d11 = v0 @ v0, v0 @ v1, v1 @ v1
            d20, d21 = v2 @ v0, v2 @ v1
            den = d00 * d11 - d01 * d01
            u = (d11 * d20 - d01 * d21) / den
            v = (d00 * d21 - d01 * d20) / den
            inside = (u >= -1e-9) & (v >= -1e-9) & (u + v <= 1 + 1e-9)
            coincident = np.isclose(others, a).all(1) | np.isclose(others, b).all(1) | \
                np.isclose(others, c).all(1)
            is_ear = not (inside & ~coincident).any()
        if is_ear:
            tris.append((ia, ib, ic))
            idx.pop(i % n)
            guard = 0
        else:
            i += 1
    tris.append(tuple(idx))
    return pts, tris


# ---------------------------------------------------------------------------
# 3D meshes (list of triangles, each a (3, 3) array)
# ---------------------------------------------------------------------------
def extrude(outer, holes=(), z0=0.0, z1=1.0):
    pts, tris = triangulate(outer, holes)
    out = []
    for (a, b, c) in tris:
        pa, pb, pc = pts[a], pts[b], pts[c]
        out.append(np.array([[*pa, z1], [*pb, z1], [*pc, z1]]))   # top (CCW from above)
        out.append(np.array([[*pa, z0], [*pc, z0], [*pb, z0]]))   # bottom
    outer = outer if _area(outer) > 0 else list(reversed(outer))
    rings = [outer] + [h if _area(h) < 0 else list(reversed(h)) for h in holes]
    for ring in rings:
        for k in range(len(ring)):
            (x1, y1), (x2, y2) = ring[k], ring[(k + 1) % len(ring)]
            out.append(np.array([[x1, y1, z0], [x2, y2, z0], [x2, y2, z1]]))
            out.append(np.array([[x1, y1, z0], [x2, y2, z1], [x1, y1, z1]]))
    return out


def transform(mesh, matrix=np.eye(3), offset=(0, 0, 0)):
    m = np.asarray(matrix, dtype=float)
    flip = np.linalg.det(m) < 0
    out = []
    for t in mesh:
        t2 = t @ m.T + np.asarray(offset, dtype=float)
        out.append(t2[[0, 2, 1]] if flip else t2)
    return out


# Maps a profile drawn in (x, z) and extruded along +w into world (x, y=w, z)
XZ_PROFILE = np.array([[1, 0, 0], [0, 0, 1], [0, 1, 0]])


def write_stl(path, mesh, name):
    with open(path, 'wb') as f:
        header = f'{name} - rover parametric part (mm)'.encode()[:80]
        f.write(header.ljust(80, b' '))
        f.write(struct.pack('<I', len(mesh)))
        for t in mesh:
            n = np.cross(t[1] - t[0], t[2] - t[0])
            ln = np.linalg.norm(n)
            n = n / ln if ln > 0 else n
            f.write(struct.pack('<12fH', *n, *t[0], *t[1], *t[2], 0))


def check_mesh(mesh, name):
    """Every directed edge must be matched by its reverse (closed, oriented)."""
    key = lambda p: tuple(np.round(p, 5))
    edges = {}
    volume = 0.0
    for t in mesh:
        volume += np.dot(t[0], np.cross(t[1], t[2])) / 6.0
        for i in range(3):
            e = (key(t[i]), key(t[(i + 1) % 3]))
            edges[e] = edges.get(e, 0) + 1
    bad = sum(1 for (a, b), n in edges.items() if edges.get((b, a), 0) != n)
    status = 'OK' if bad == 0 and volume > 0 else 'FAIL'
    print(f'  [{status}] {name:15s} {len(mesh):6d} triangles, volume {volume / 1000:8.1f} cm3'
          + (f', {bad} unmatched edges' if bad else ''))
    return status == 'OK'


# ---------------------------------------------------------------------------
# Parts
# ---------------------------------------------------------------------------
class Rover:
    def __init__(self, dims):
        mm = lambda v: v * 1000.0
        c, w, mo, ca, li, cam = (dims['chassis'], dims['wheel'], dims['motor'],
                                 dims['caster'], dims['lidar'], dims['camera'])
        self.L, self.W = mm(c['length']), mm(c['width'])
        self.t = mm(c['plate_thickness'])
        self.r_corner = mm(c['corner_radius'])
        self.inset = mm(c['standoff_inset'])
        self.deck = mm(c['deck_spacing'])
        self.plate_z = mm(c['lower_plate_z'])
        self.wheel_r, self.wheel_w = mm(w['radius']), mm(w['width'])
        self.tire_t = mm(w['tire_thickness'])
        self.shaft_d, self.shaft_flat = mm(w['shaft_diameter']), mm(w['shaft_flat'])
        self.motor_d = mm(mo['diameter'])
        self.motor_holes = mm(mo['mount_hole_spacing'])
        self.caster_x = mm(ca['x_offset'])
        self.caster_h = mm(ca['body_height'])
        self.lidar_x, self.lidar_size = mm(li['x']), mm(li['size'])
        self.lidar_riser_h = mm(li['riser_height'])
        self.cam_x, self.cam_w = mm(cam['x']), mm(cam['width'])
        self.cam_riser_h = mm(cam['riser_height'])
        # derived
        self.axle_drop = self.plate_z - self.wheel_r          # plate bottom -> motor axis
        self.bracket_t = 4.0
        self.bracket_w = 32.0
        self.bracket_flange = 24.0

    # ---- hole patterns (plate coordinates, mm) ---------------------------
    def standoff_holes(self):
        x, y = self.L / 2 - self.inset, self.W / 2 - self.inset
        return [circle(sx * x, sy * y, M3 / 2) for sx in (1, -1) for sy in (1, -1)]

    def bracket_holes(self):
        y = self.W / 2 - self.bracket_flange / 2 - 2.0
        return [circle(sx * 10.0, sy * y, M3 / 2) for sx in (1, -1) for sy in (1, -1)]

    def caster_holes(self):
        return [circle(sx * self.caster_x, sy * 12.0, M3 / 2) for sx in (1, -1) for sy in (1, -1)]

    # ---- parts ------------------------------------------------------------
    def base_plate(self):
        holes = self.standoff_holes() + self.bracket_holes() + self.caster_holes()
        # Raspberry Pi 5 (58 x 49 mm hole pattern), rear half
        pi_cx = -50.0
        holes += [circle(pi_cx + sx * 29.0, sy * 24.5, M25 / 2) for sx in (1, -1) for sy in (1, -1)]
        # battery strap slots (front half)
        holes += [slot(27.5, sy * (self.W / 2 - 17.0), 26.0, 4.0) for sy in (1, -1)]
        # motor / encoder cable pass-through
        holes += [slot(0.0, sy * 22.0, 14.0, 9.0, angle_deg=90) for sy in (1, -1)]
        # camera riser: 2x M3 + 1/4" tripod screw access
        holes += [circle(self.cam_x, sy * 25.0, M3 / 2) for sy in (1, -1)]
        holes += [circle(self.cam_x, 0.0, QUARTER / 2)]
        outer = rounded_rect(0, 0, self.L, self.W, self.r_corner)
        return extrude(outer, holes, 0, self.t)

    def top_plate(self):
        holes = self.standoff_holes()
        lx = self.lidar_x
        holes += [circle(lx + sx * 26.0, sy * 26.0, M3 / 2) for sx in (1, -1) for sy in (1, -1)]
        holes += [circle(lx, 0.0, 10.0)]                                   # lidar cable
        # accessory grid (motor driver, buck converter, switch...)
        for x in (50.0, 70.0, -70.0, -55.0):
            if abs(x - lx) < 45:
                continue
            for y in (-40.0, -20.0, 0.0, 20.0, 40.0):
                holes.append(circle(x, y, M3 / 2))
        holes += [slot(85.0, 0.0, 30.0, 8.0, angle_deg=90)]                 # front cable slot
        outer = rounded_rect(0, 0, self.L, self.W, self.r_corner)
        return extrude(outer, holes, 0, self.t)

    def wheel_hub(self):
        """Printed outer face down. z = 0 is the OUTER face, z = width faces the chassis."""
        r_rim = self.wheel_r - self.tire_t
        web_t = 4.0
        hub_r = 7.0
        d_hole = d_shape(0, 0, self.shaft_d + 0.2, self.shaft_flat)
        spokes = [circle(18.5 * math.cos(a), 18.5 * math.sin(a), 5.5)
                  for a in np.linspace(0, 2 * math.pi, 6, endpoint=False)]
        mesh = []
        mesh += extrude(circle(0, 0, r_rim - 0.01, 96), [circle(0, 0, r_rim - 3.0, 96)], 0, self.wheel_w)
        # web overlaps rim and hub slightly so slicers merge the shells
        mesh += extrude(circle(0, 0, r_rim - 2.5, 96), spokes + [circle(0, 0, hub_r - 0.5, 40)], 0, web_t)
        mesh += extrude(circle(0, 0, hub_r, 40), [d_hole], 0, self.wheel_w)
        return mesh

    def tire_tpu(self):
        r_rim = self.wheel_r - self.tire_t
        return extrude(circle(0, 0, self.wheel_r, 120), [circle(0, 0, r_rim - 0.2, 120)], 0, self.wheel_w)

    def motor_bracket(self):
        """L bracket. Print flange-down. Flange bolts under the lower plate, the wall holds
        the gearbox face (2x M3 + 7 mm boss). Print frame: y = 0 is the outer face."""
        w, t, fl = self.bracket_w, self.bracket_t, self.bracket_flange
        wall_h = self.axle_drop + self.motor_d / 2 + 4.0
        # flange (on the bed)
        flange_holes = [circle(sx * 10.0, fl / 2 + 2.0, M3 / 2) for sx in (1, -1)]
        mesh = extrude(rect(0, fl / 2, w, fl), flange_holes, 0, t)
        # wall (profile in x/z, thickness along +y)
        prof = rounded_rect(0, wall_h / 2, w, wall_h, 1.0, 2)
        prof = [(x, max(z, 0.0)) for x, z in rect(0, wall_h / 2, w, wall_h)]
        holes = [circle(0, self.axle_drop, 3.75), ] + \
                [circle(sx * self.motor_holes / 2, self.axle_drop, M3 / 2) for sx in (1, -1)]
        wall = extrude(prof, holes, 0, t)
        mesh += transform(wall, XZ_PROFILE)
        return mesh

    def caster_spacer(self):
        h = self.plate_z - self.caster_h
        holes = [circle(0, sy * 12.0, M3 / 2) for sy in (1, -1)]
        return extrude(rounded_rect(0, 0, 18.0, 36.0, 4.0), holes, 0, h)

    def lidar_riser(self):
        s = self.lidar_size + 8.0
        holes = [circle(sx * 26.0, sy * 26.0, M3 / 2) for sx in (1, -1) for sy in (1, -1)]
        holes += [circle(0, 0, 10.0)]
        # lighten
        holes += [slot(0, sy * 17.0, 26.0, 7.0) for sy in (1, -1)]
        return extrude(rounded_rect(0, 0, s, s, 6.0), holes, 0, self.lidar_riser_h)

    def camera_riser(self):
        holes = [circle(0, sy * 25.0, M3 / 2) for sy in (1, -1)] + [circle(0, 0, QUARTER / 2)]
        return extrude(rounded_rect(0, 0, 20.0, 64.0, 4.0), holes, 0, self.cam_riser_h)

    def standoff(self):
        return extrude(circle(0, 0, 3.5, 24), [circle(0, 0, 1.6, 16)], 0, self.deck)


PARTS = {
    # name: (quantity, material, note)
    'base_plate': (1, 'PETG/PLA', '100% flat, 4 perimeters, 30% infill'),
    'top_plate': (1, 'PETG/PLA', '100% flat, 4 perimeters, 30% infill'),
    'wheel_hub': (2, 'PETG', 'outer face down, 5 perimeters for the D-hole'),
    'tire_tpu': (2, 'TPU 95A', 'stretch over the hub rim'),
    'motor_bracket': (2, 'PETG', 'flange down, 40% infill'),
    'caster_spacer': (2, 'PETG/PLA', ''),
    'lidar_riser': (1, 'PETG/PLA', ''),
    'camera_riser': (1, 'PETG/PLA', ''),
    'standoff': (4, 'PETG/PLA', 'or use M3x60 brass standoffs'),
}


# ---------------------------------------------------------------------------
# Rover4: 4WD + front (Ackermann) steering
#
# Parts are modelled in the robot's own frames (millimetres):
#   base_link  = rear-axle centre, z relative to the axle   (plates, beam, mounts)
#   steering   = kingpin axis of the left front knuckle      (knuckles)
#   wheel      = wheel centre, axle along y                  (hubs, tires)
# so the same geometry is used as an exact visual mesh in the simulator; for printing
# each part is rotated onto its flat face and moved onto the bed.
# ---------------------------------------------------------------------------
RX_PI = np.diag([1.0, -1.0, -1.0])                       # 180 deg about x (flip upside down)
MIRROR_Y = np.diag([1.0, -1.0, 1.0])                     # left <-> right
WHEEL_Z_TO_Y = np.array([[1, 0, 0], [0, 0, -1], [0, 1, 0]], dtype=float)  # axis z -> -y


def convex_hull(points):
    pts = sorted(set(points))
    if len(pts) < 3:
        return pts

    def cross(o, a, b):
        return (a[0] - o[0]) * (b[1] - o[1]) - (a[1] - o[1]) * (b[0] - o[0])
    lower, upper = [], []
    for p in pts:
        while len(lower) >= 2 and cross(lower[-2], lower[-1], p) <= 0:
            lower.pop()
        lower.append(p)
    for p in reversed(pts):
        while len(upper) >= 2 and cross(upper[-2], upper[-1], p) <= 0:
            upper.pop()
        upper.append(p)
    return lower[:-1] + upper[:-1]


def arc(cx, cy, r, a0_deg, a1_deg, n=8):
    return [(cx + r * math.cos(math.radians(a0_deg + (a1_deg - a0_deg) * i / n)),
             cy + r * math.sin(math.radians(a0_deg + (a1_deg - a0_deg) * i / n))) for i in range(n + 1)]


def for_print(mesh, rotation=np.eye(3)):
    """Rotate a part onto its flat face and put it on the bed, centred at x = y = 0."""
    m = transform(mesh, rotation)
    pts = np.concatenate(m)
    lo, hi = pts.min(0), pts.max(0)
    return transform(m, np.eye(3), (-(lo[0] + hi[0]) / 2, -(lo[1] + hi[1]) / 2, -lo[2]))
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

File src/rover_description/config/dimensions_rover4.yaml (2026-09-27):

# ---------------------------------------------------------------------------
# Rover4: 4WD, front-wheel (Ackermann) steering. Single source of truth.
#
# Read by:
#   * urdf/rover4.urdf.xacro        (simulation / TF / Nav2 footprint)
#   * hardware/generate_parts.py    (3D-printable STL parts)
#
# Reference point: base_link sits on the REAR axle centre (bicycle-model convention for
# car-like robots). All values in METERS / KILOGRAMS / RADIANS.
# ---------------------------------------------------------------------------

chassis:
  rear_x: -0.040           # lower deck rear edge (from the rear axle)
  front_x: 0.240           # lower deck front edge
  width: 0.150             # lower deck width behind the steering area
  front_width: 0.090       # narrower nose so the steered front wheels have room
  narrow_from_x: 0.150     # where the nose starts
  split_x: 0.100           # the deck is printed in two halves joined here (220 mm bed)
  plate_thickness: 0.005
  corner_radius: 0.012
  lower_plate_z: 0.060     # bottom of the lower deck above the ground
  deck_spacing: 0.060      # standoff length
  top_length: 0.200        # upper deck (one piece)
  top_width: 0.150
  top_x: 0.100             # upper deck centre (from the rear axle)
  mass_lower: 1.40         # lower deck + motors + battery + electronics + servo
  mass_upper: 0.25

wheel:
  radius: 0.0425           # 85 mm incl. TPU tire
  width: 0.030
  tire_thickness: 0.004
  mass: 0.08
  shaft_diameter: 0.003    # N20 D-shaft
  shaft_flat: 0.0005

axles:
  wheelbase: 0.200         # rear axle -> front axle
  track: 0.220             # wheel centre to wheel centre

steering:
  kingpin_y: 0.080         # kingpin (steering axis) distance from the centre line
  limit: 0.52              # max steering angle (30 deg)
  arm_length: 0.025        # knuckle steering arm (Ackermann linkage)
  servo: MG996R            # 40.7 x 19.7 x 42.9 mm, 13 kg.cm
  servo_x: 0.170           # servo output shaft position
  horn_length: 0.015

motor:                     # 4x N20 micro gear motor with hall encoder, 12 V ~200 rpm
  width: 0.012
  height: 0.010
  length: 0.034            # gearbox + motor + encoder
  mass: 0.015

lidar:                     # Slamtec RPLIDAR S2M1 (DFRobot): DTOF, 32 kHz, 0.05-30 m
  x: 0.100
  size: 0.077              # 77 x 77 mm body
  height: 0.039
  riser_height: 0.010
  scan_plane: 0.027        # optical centre above the mounting face (check your unit)
  mount_hole_spacing: 0.060  # riser -> lidar hole square; VERIFY against the S2 datasheet
  mass: 0.19
  min_range: 0.05
  max_range: 30.0
  samples: 1600            # real S2: 3200 per rev (0.1125 deg); halved in sim for speed
  rate: 10.0

camera:                    # Intel RealSense D435i (RGB-D + BMI055 IMU)
  x: 0.2275                # camera centre (from the rear axle)
  width: 0.090
  depth: 0.025
  height: 0.025
  riser_height: 0.008
  pitch: 0.0
  mass: 0.072
  hfov: 1.518              # depth 87 deg
  image_width: 424
  image_height: 240
  min_depth: 0.2
  max_depth: 6.0
  rate: 15.0
  imu_rate: 200.0          # D435i gyro 200/400 Hz

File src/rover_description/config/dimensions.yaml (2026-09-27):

# ---------------------------------------------------------------------------
# Rover dimensions: the single source of truth.
#
# Read by:
#   * urdf/rover.urdf.xacro        (simulation / TF / Nav2 footprint)
#   * hardware/generate_parts.py   (3D-printable STL parts)
#
# All values are in METERS and KILOGRAMS. If you change a value, re-run
# hardware/generate_parts.py and rebuild the workspace.
# ---------------------------------------------------------------------------

chassis:
  length: 0.200            # X, fits a 220x220 mm print bed
  width: 0.150             # Y
  plate_thickness: 0.004
  corner_radius: 0.015
  lower_plate_z: 0.052     # bottom of the lower deck above the ground
  deck_spacing: 0.060      # M3 standoff length between lower and upper deck
  standoff_inset: 0.012    # standoff hole distance from the plate edge
  mass_lower: 0.45         # lower deck + motors + battery + electronics
  mass_upper: 0.10         # upper deck

wheel:
  radius: 0.035            # outer radius incl. TPU tire
  width: 0.024
  tire_thickness: 0.003
  gap: 0.004               # gap between chassis side and wheel inner face
  mass: 0.06
  shaft_diameter: 0.004    # JGA25-370 D-shaft
  shaft_flat: 0.0005       # depth of the D flat

motor:                     # JGA25-370 gear motor with hall encoder
  diameter: 0.025
  length: 0.068            # gearbox + motor + encoder
  mount_hole_spacing: 0.017
  mass: 0.10

caster:                    # commercial 3/4" metal ball caster on a printed spacer
  ball_radius: 0.0095
  body_height: 0.025       # ball caster height (ground -> mounting face), measure yours!
  x_offset: 0.072          # front caster at +x, rear caster at -x

lidar:                     # RPLIDAR C1 (or A1/LD19, adjust size)
  x: -0.010
  size: 0.056
  height: 0.041
  riser_height: 0.010
  scan_plane: 0.026        # optical centre above the mounting face
  mass: 0.11
  min_range: 0.12
  max_range: 12.0
  samples: 360
  rate: 10.0

camera:                    # Intel RealSense D435 / OAK-D Lite class RGB-D camera
  x: 0.088                 # camera centre, from the chassis centre
  width: 0.090
  depth: 0.025
  height: 0.025
  riser_height: 0.008
  pitch: 0.0               # positive = tilted down (rad)
  mass: 0.07
  hfov: 1.518              # 87 deg
  image_width: 424          # D435 native 424x240 mode, light on the simulator
  image_height: 240
  min_depth: 0.2
  max_depth: 6.0
  rate: 15.0

imu:                       # BNO055 / MPU-6050 / ICM-20948 breakout
  x: 0.0
  y: 0.0

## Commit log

2026-09-27 Initial release: 3D-printable autonomous rover for ROS 2 Jazzy
    - rover_description: parametric URDF/xacro driven by a single dimensions.yaml
    - rover_gazebo: Gazebo Harmonic world with rooms, furniture and low obstacles
    - rover_navigation: EKF, SLAM Toolbox, AMCL, Nav2 (Smac 2D + MPPI, depth voxel layers)
    - rover_control: keyboard teleop, manual/auto mode manager, frontier explorer,
    waypoint patrol example, simulation sensor adapter
    - rover_bringup: simulation and real-robot launch files, RViz config
    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
    [base_plate.stl, camera_riser.stl, caster_spacer.stl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]
2026-09-27 fix(rover_control): exit cleanly on Ctrl-C
    frontier_explorer could exit with code 1 when the stack was stopped
    while it was working:
    - the TF lookup in the planning timer waited up to 0.1 s on sim time;
    if Gazebo stopped first, the clock froze during shutdown. The lookup
    is now non-blocking and the next planning cycle simply retries.
    - an exception raised by a callback that was still running after
    Ctrl-C (for example publishing on an invalidated context) escaped
    main(). Errors raised once shutdown has begun are now treated as a
    normal exit; errors while running are still raised.
    The same shutdown handling is applied to mode_manager and
    sim_sensor_adapter, and ExternalShutdownExce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
2026-09-27 feat: add rover4, a 4WD robot with Ackermann steering
    A second, car-like robot next to the 2WD rover, selected with robot:=rover4
    in every launch file. It shares the autonomy stack (topics, EKF, SLAM,
    mode manager, explorer).
    Robot
    - 285 x 250 mm, 4 N20 drive motors, MG996R-steered front wheels
    - RPLIDAR S2M1 (30 m) and RealSense D435i, whose IMU replaces the
    separate IMU board
    - dimensions_rover4.yaml drives both the URDF and the printed parts
    - 15 new printable parts (split lower deck, knuckles, axle beam, servo
    mount, tie rods...), all fitting a 220 x 220 mm bed
    Simulation and navigation
    - Gazebo AckermannSteering system on the same /cmd_vel and odometry topics
    - Nav2: Smac Hybrid-A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
    [base_front.stl, base_rear.stl, camera_riser.stl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]

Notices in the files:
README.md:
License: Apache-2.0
